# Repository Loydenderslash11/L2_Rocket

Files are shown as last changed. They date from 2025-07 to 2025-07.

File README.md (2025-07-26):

# Project MightyMouse – Level 2 High-Power Rocket

Welcome to the repository for **Project MightyMouse**, my custom-designed **Level 2 high-power rocket** built for TRA/NAR certification. This rocket was developed using 3D CAD modeling, PETG printing, carbon fiber reinforcement, and professional avionics. It's powered by a Cesaroni J520 Skidmark and is capable of reaching altitudes around 5,000 feet.

---

##  Rocket Specifications

| Attribute | Specification |
|---|---|
| **Rocket Name** | Project MightyMouse |
| **Total Length** | 45 inches |
| **Diameter** | 45 mm (≈ 1.77 in) |
| **Dry Weight** | 1.0 kg (without motor) |
| **Flight Weight** | 1.8 kg (with motor) |
| **Motor** | Cesaroni P38-6XL Skidmark (J520) |
| **Estimated Altitude**| ~5,000 feet AGL |
| **Recovery System** | Dual-deploy (drogue at apogee, main at 4500 ft) |
| **Airframe Material** | Carbon fiber cloth over PVC core |
| **Fins** | Custom design from RockSim, modeled in Fusion 360 |
| **Avionics** | MissileWorks RRC3 + AltusMetrum EasyMini |

---

##  Construction Details

- **Airframe:** PVC pipe wrapped in carbon fiber cloth, hardened with epoxy resin
- **Modules:** All modules 3D printed in PETG for strength and temperature resistance
- **Fins:** Aerodynamically simulated in RockSim and modeled in Fusion 360, all 3d printed with PETG
- **Avionics Bay:** Houses dual-deployment electronics and battery compartment

---
## BOM (Bill of Material)

This table includes pricing and purchase links for all components used in the rocket build. Custom or 3D-printed components are not listed.

| Category | Item | Est. Price | Purchase Link |
|---|---|---|---|
| **Motor** | Cesaroni P38‑6XLG Skidmark (J520) | $170 | [Apogee Rockets](https://www.apogeerockets.com/Rocket_Motors/Cesaroni_Propellant_Kits/38mm_Motors/6XL-Grain_Motors/Cesaroni_P38-6XLG_Skidmark_J520) |
| **Filament** | eSUN PETG 1 kg spool | $21.99 | [Amazon - eSUN PETG](https://www.amazon.com/eSUN-Filament-Dimensional-Accuracy-Printing/dp/B07FXD1K8Y) |
| **Epoxy Kit** | West System 105-B + 206-B (1 gal kit) | $176.21 | [Amazon - West System Epoxy Kit](https://www.amazon.com/West-System-105-B-Epoxy-Hardener/dp/B0C3MY967W) |
| **Resin Only** | West System 105-B Resin (1 gal) | $114.03 | [Fisheries Supply - 105-B Resin](https://www.fisheriessupply.com/west-system-105-epoxy-resin/105-b) |
| **Altimeter** | MissileWorks RRC3 | ~$101 | [MissileWorks / Apogee Rockets](https://www.apogeerockets.com/Electronics-Payloads/Altimeters/RRC3-Sport-Altimeter) |
| **Backup Altimeter** | AltusMetrum EasyMini | ~$100 | [AltusMetrum](https://altusmetrum.org/EasyMini/) |
| **Battery** | 2S 7.4V 30C LiPo Battery | $8 | [2S 7.4V 30C LiPo Battery](https://www.amazon.com/Crazepony-400mAh-Battery-Racing-Quadcopter/dp/B07PF8ZJKX) |
| **Shock Cord** | Kevlar Shock Cord (20ft) | $34.99 | [Apogee - Kevlar Cord](https://www.apogeerockets.com/Building-Supplies/Shock-Cord/Kevlar-Shock-Cord-4500-20-feet-long-2-loops) |
| **Drogue Chute** | 12″ Drogue Parachute | $20 | [Apogee - Parachute](https://www.apogeerockets.com/Building-Supplies/Parachutes/Drogue-Parachutes/Explorer-12in-Drogue-Chute) |
| **Main Chute** | 24–30″ Main Parachute | $15 | [Apogee - Parachute](https://www.apogeerockets.com/Building-Supplies/Parachutes/Larger-than-24in/30in-Printed-Nylon-Parachute) |
| **Eyebolts** | M4 eyebolts, washers, locknuts | $12 | [Amazon - Eyebolt Kit](https://www.amazon.com/Stainless-Steel-Bolts-Washers-Lifting/dp/B0BQ3C7M73?th=1) |
| **E-matches** | Igniter pack (Slim Gem Starters) | $24 | [Apogee - Starters](https://www.apogeerockets.com/Rocket_Motors/Motor_Starters/Slim_Gem_Starters) |
| **Threadlocker** | Loctite Blue 242 (6ml) | $8 | [Amazon - Loctite 242](https://www.amazon.com/Loctite-Threadlocker-Removable-Adhesive-Single/dp/B000I1RSNS) |

---

**Notes:**
- Prices are as of July 2025 and may change slightly with location and vendor.
- PETG, epoxy, and batteries are available on Amazon and local hardware stores.
- Motor and altimeters are being be purchased from certified high-power rocketry vendors like Apogee, Wildman, or AltusMetrum.

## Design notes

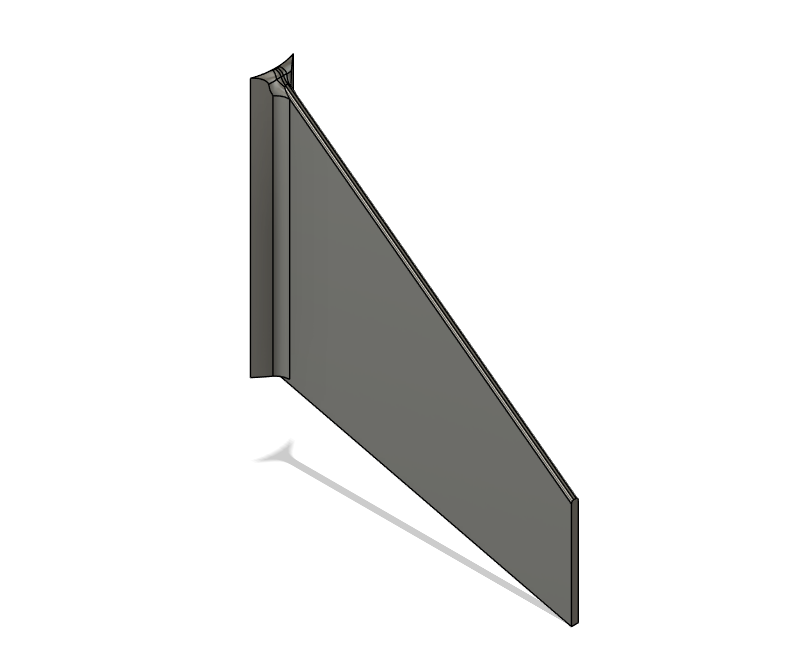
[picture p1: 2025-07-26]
Pictures/FinDesign.png

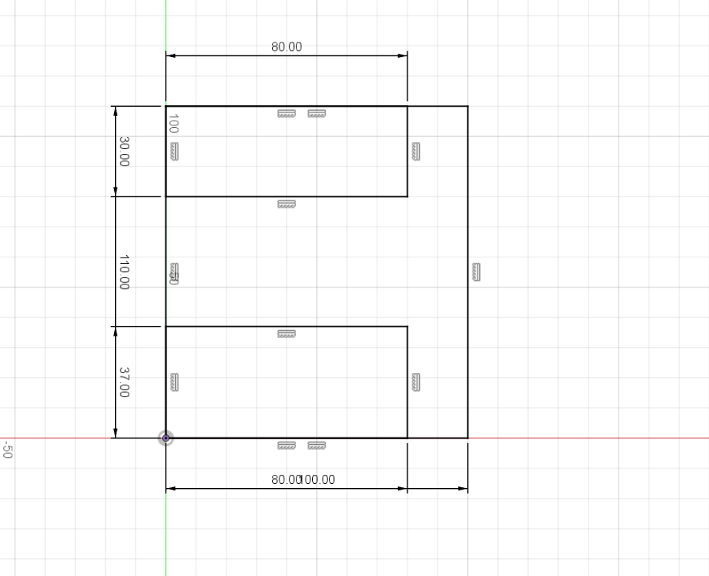
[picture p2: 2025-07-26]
Pictures/GroundStationDiameters.png

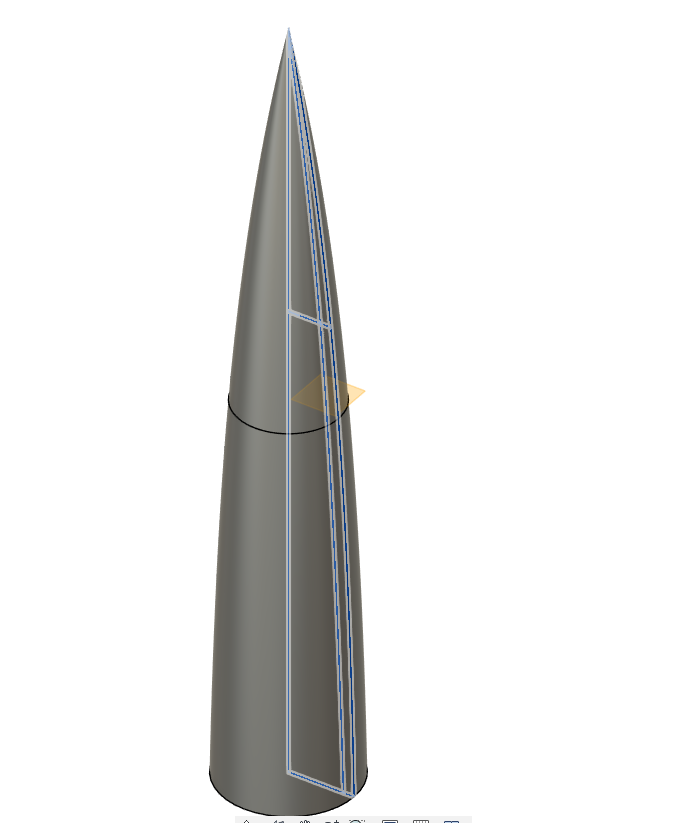
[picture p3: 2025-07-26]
Pictures/Nosecone.png

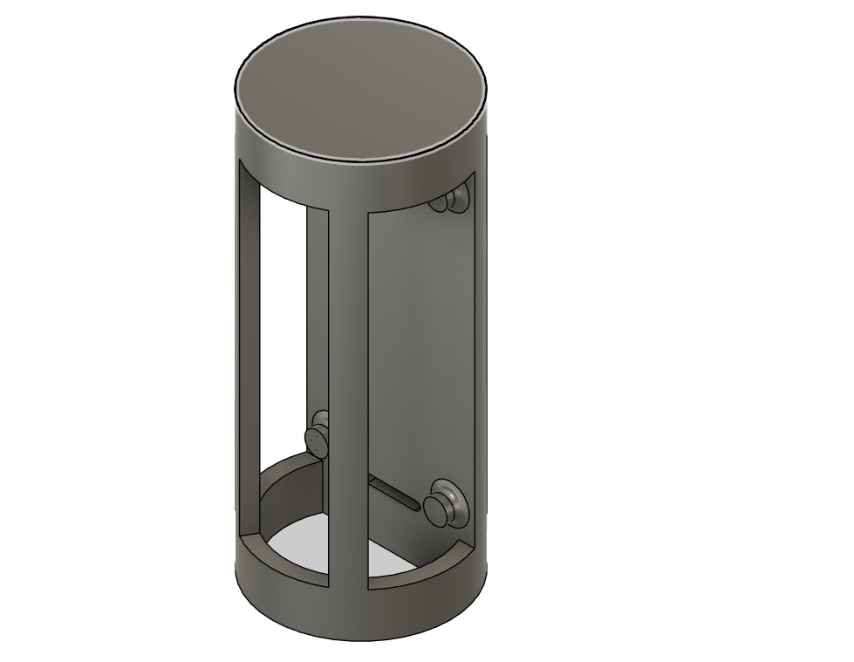
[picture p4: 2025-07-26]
Pictures/AvionicBay.png

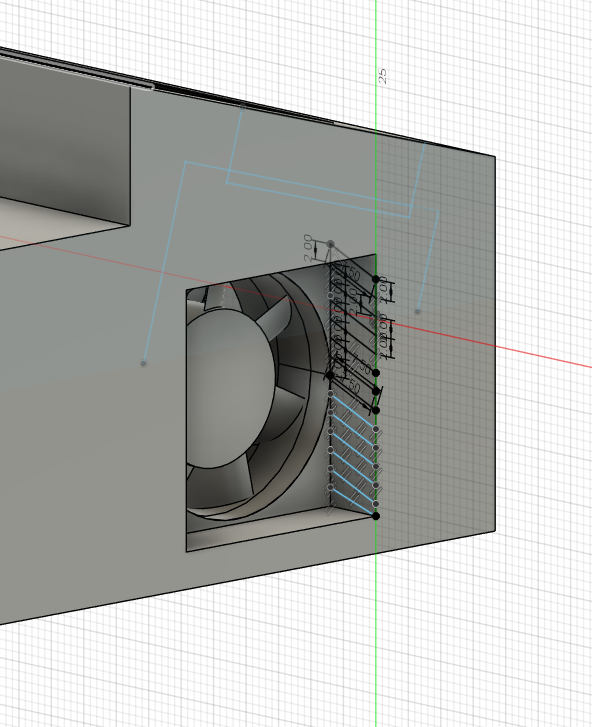
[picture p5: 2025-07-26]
Pictures/GroundStationCooling.png

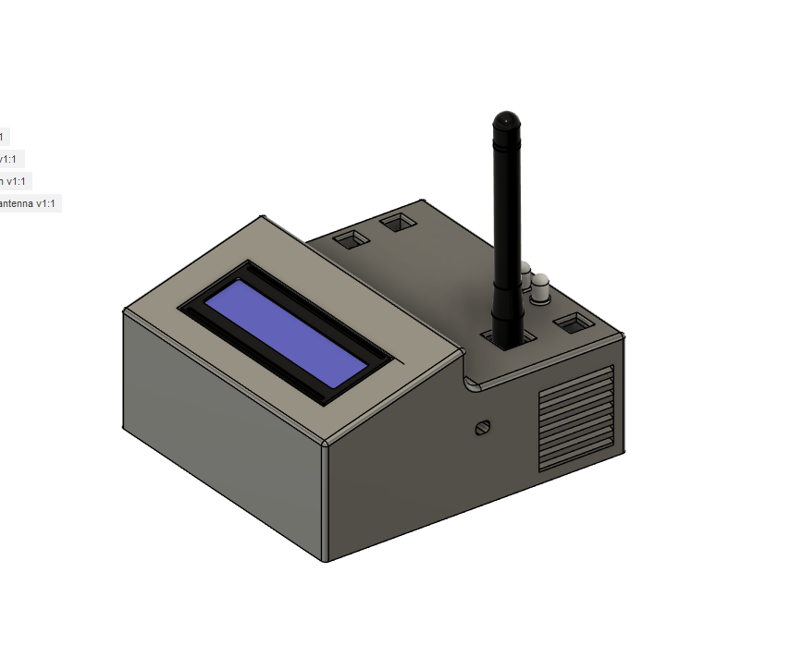
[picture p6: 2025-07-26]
Pictures/GroundStationIsometric.png

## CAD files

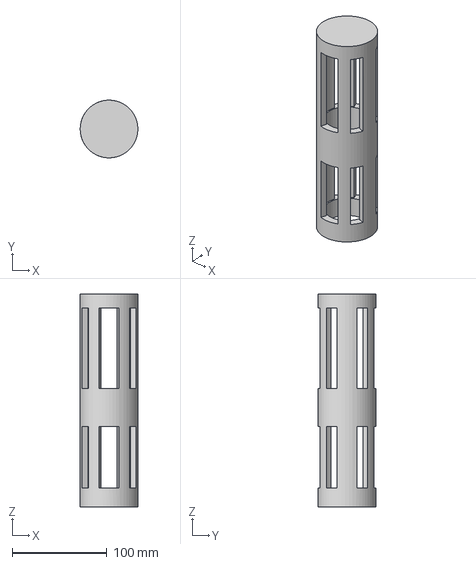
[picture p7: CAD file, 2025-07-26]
CAD/RocketMotorShell v2.step
60.9 x 61.0 x 225.0 mm

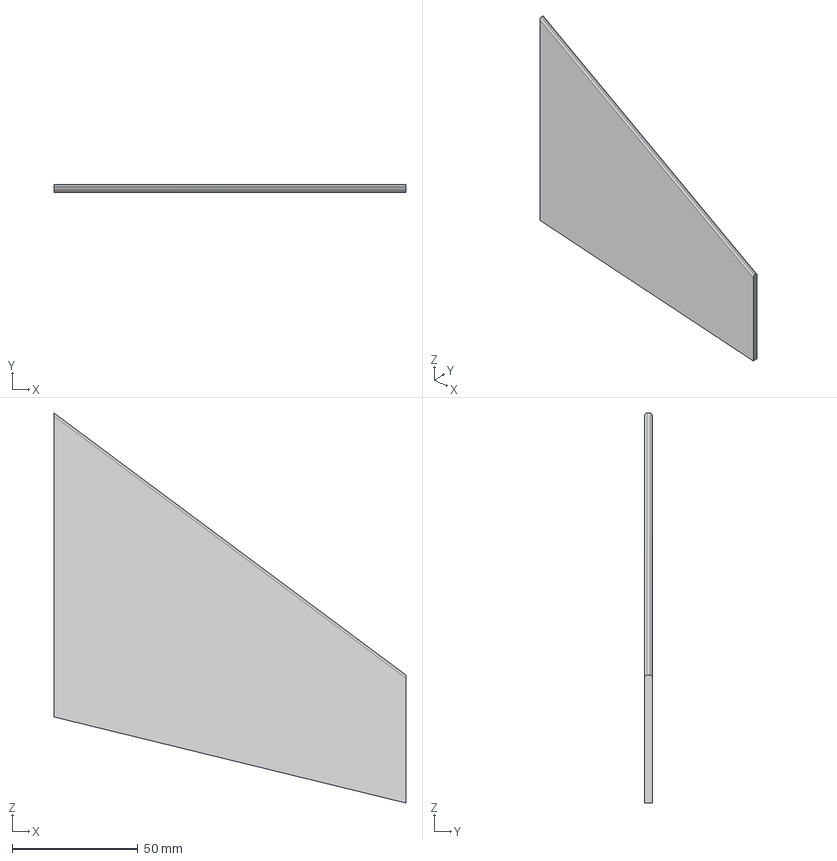
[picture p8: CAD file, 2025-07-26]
CAD/Rocket_Fin_GoldRush v3.step
139.7 x 3.18 x 154.8 mm

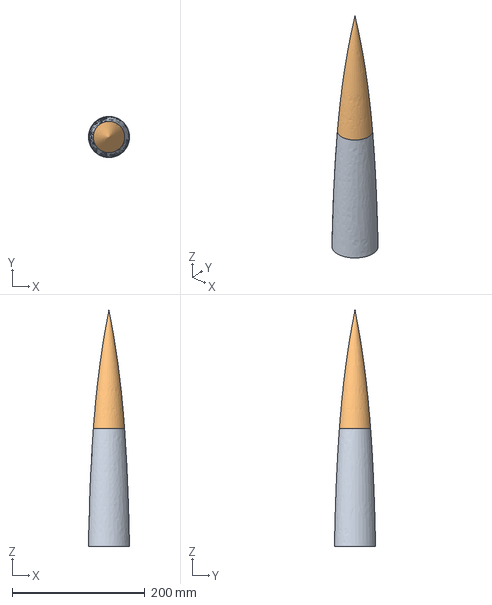
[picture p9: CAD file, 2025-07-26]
CAD/RocketNose v1.step
61.9 x 62.0 x 355.6 mm

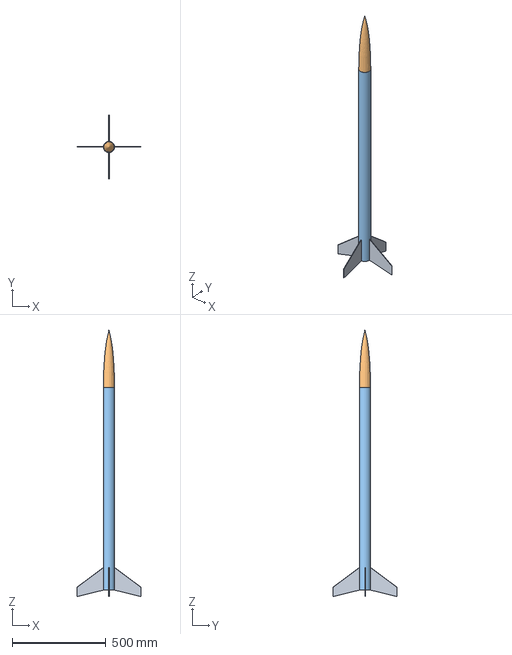
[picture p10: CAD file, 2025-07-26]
CAD/Rocket_Tube_GoldRush v2.step
338.8 x 338.8 x 1419.0 mm
Rocket_Fin_GoldRush x 4
Rocket_Nose_GoldRush

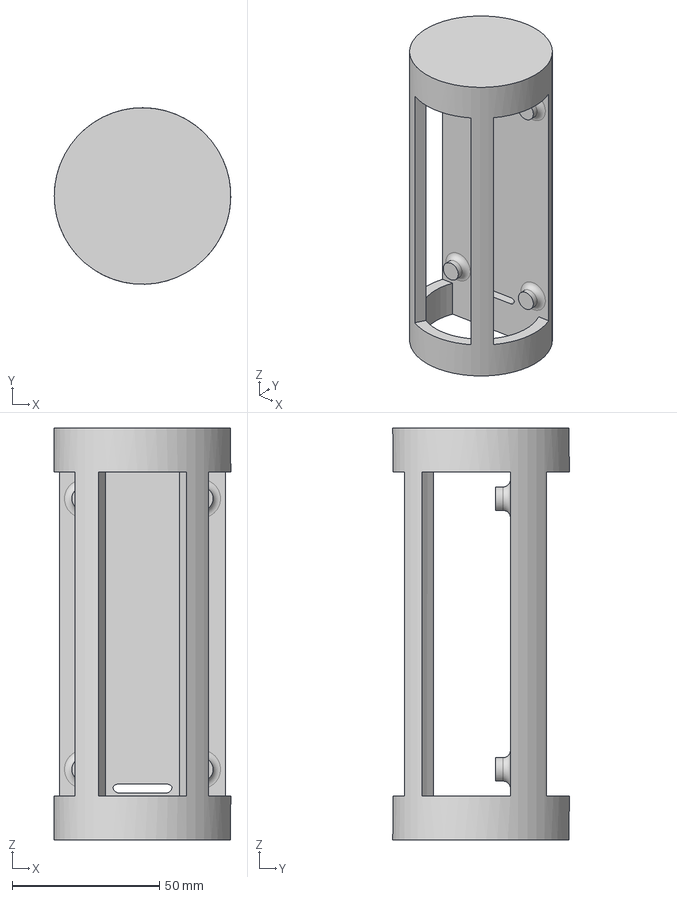
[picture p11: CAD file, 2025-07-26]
CAD/GR AV Bay V.2 v1.step
60.0 x 60.0 x 140.0 mm

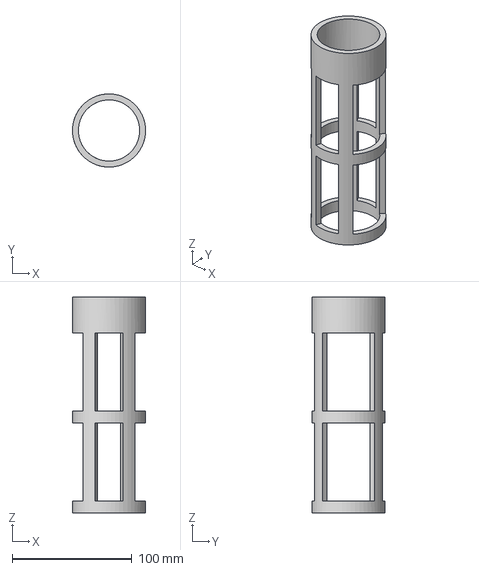
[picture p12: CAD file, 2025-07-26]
CAD/TopParachuteBay v1.step
60.9 x 61.0 x 180.0 mm

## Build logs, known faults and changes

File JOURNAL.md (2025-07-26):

---
title: "Project MightyMouse"
author: "Kiyanoosh Kesheh"
description: "Mach 0.5 L2 Rocket!"
started at: "2025-03-14"
---

## Week 1 (03/14/2025)

- Began initial concept for Level 2 high-power rocket
- Chose project name: **Project MightyMouse**
- Selected motor: **Cesaroni P38-6XLG Skidmark (J520)**
- Estimated altitude: ~5000 ft, dual deployment planned
- Outlined recovery system and general airframe configuration


---

## Week 2 (03/21/2025)

- Designed fin geometry in **RockSim**
- Exported fin profiles to **Fusion 360** for CAD modeling
- Chose airframe material: **carbon fiber cloth over PVC pipe**
- Planned electronics bay and bulkhead layout
- Reviewed flight simulation data for stability and mass predictions


---

## Week 3 (03/28/2025)

- Finalized 3D models of **fins** and **nose cone** in Fusion 360
- 3D printed test versions of both parts using **PETG**
- Verified dimensional accuracy and fit with airframe
- Integrated updated fin geometry into RockSim model
- Completed airframe segment designs with modular approach in Fusion


---

## Week 4 (06/07/2025)

### 3D Print Settings (Fins & Nose Cone):

* **Nozzle Temp:** 230°C  
* **Bed Temp:** 80°C  
* **Infill:** 20% Grid  
* **Layer Height:** 0.2 mm  
* **Slicer:** Cura



- Printed full-size nose cone and fins successfully in PETG
- Performed basic fit checks on components
- Started designing internal structures for recovery system
- Reviewed structural options for motor retention and centering rings

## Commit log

2025-07-26 Rename image (6).png to GroundStationDiameters.png
2025-07-26 Rename image (7).png to GroundStationSideView.png
2025-07-26 Rename image (8).png to GroundStationIsometric.png
2025-07-26 Rename image (9).png to GroundStationCooling.png
2025-07-26 Rename image (11).png to MotorAdapterShell.png
